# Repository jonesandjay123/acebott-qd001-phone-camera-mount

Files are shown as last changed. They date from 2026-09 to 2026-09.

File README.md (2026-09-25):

# ACEBOTT QD001 Phone Camera Mount

3D-printable, one-piece phone mount for the ACEBOTT QD001 mecanum-wheel robot car.
The phone stands upright (90°) above the battery box so its **rear camera works as the
car's forward-looking camera**; the screen faces the rear of the car.

Designed for a **Bambu Lab A1 mini**, printed upright with **no supports**.

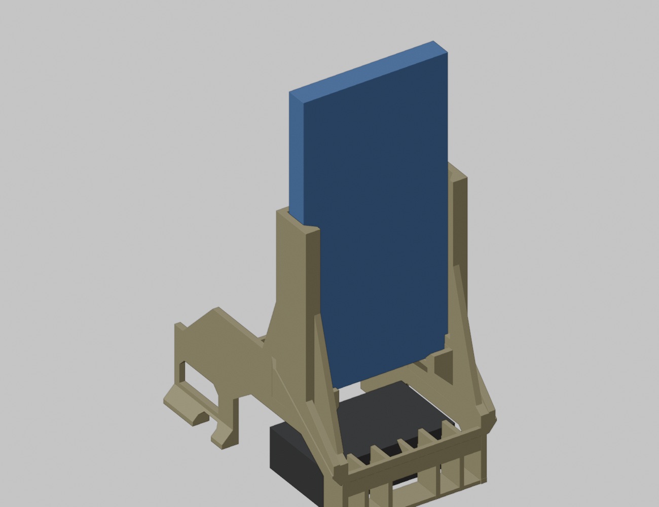
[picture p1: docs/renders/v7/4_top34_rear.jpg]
V7 rear view with phone


## Files

| Path | What it is |
|---|---|
| `models/current/ACEBOTT_QD001_PhoneMount_V7_90deg_OnePiece.stl` | **Print this.** V7, fixed 90°, one piece, 104.3 cm³, 91 × 138 × 150 mm |
| `models/current/spoiler_v9_fable_v7.blend` | Blender source of V7 (object `V7_Body`) |
| `models/legacy/ACEBOTT_QD001_PhoneMount_V6_…_DO-NOT-PRINT.stl` | V6 — tower stood on the mast and blocked the wire bundle. Kept for reference only |
| `models/legacy/FableV4_OnePiece.stl` | V4 — 35° "spoiler" version. Printed and installed; its lower half is the verified base that V6 is built on |
| `models/legacy/spoiler_v7_fable_v5_stepped-angle-concept.blend` | V5 concept: 100° tower with a 3-step (90/95/100°) tread floor. Superseded by V6 |
| `docs/DESIGN_NOTES.md` | Geometry, constraints, load path, what was verified on the real car |
| `docs/PRINTING.md` | Slicer settings, orientation, risk notes |
| `docs/images/` | Photos of V4 on the car and the annotated side view used to plan V6 |
| `docs/renders/` | Blender renders of V7, V6 and the V5 concept |
| `reference/scripts/` | Python used in Blender to build/check/export the parts (`build_v7.py` reproduces V7 from the V4 STL) |
| `reference/photos/` | Full-size photos of V4 installed |

## Phone

Sized for a Pixel with a case: slot **81.5 mm** wide, **18.5 mm** deep, phone bottom ~54 mm above
the upper chassis plate. The top ~55 mm of the phone (camera bar) is left completely free.
USB‑C cable exits downward through the open centre of the floor.

## Status

- V4: printed, installed, verified fit (USB‑C window, screw notches, battery bay, wiring).
- V6: never printed — its tower sat inside the wire-bundle space in front of the mast (see `docs/DESIGN_NOTES.md`, "Wire keep-out").
- V7: tower moved behind the mast; wire chamber proven empty by boolean check. Geometry verified in software only (watertight, no islands, bridges as V4 plus one 30 mm arch). **Not yet printed.**

## License

MIT — see `LICENSE`.

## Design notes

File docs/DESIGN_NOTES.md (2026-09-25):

# Design notes

## Origin
The mount started as a cardboard prototype built directly on the car, 3D-scanned, and turned into a
printable part (V1–V4, 35° deck). V4 was printed and installed; its lower half (side walls, USB‑C
window, screw-head notches, battery arches, DC-plug window, rear fins) is treated as verified and is
reused unchanged by every later version — later versions are built by importing `FableV4_OnePiece.stl`
into Blender and cutting/adding geometry (`reference/scripts/build_v6.py`).

## Why 90°
With the phone lying at 35° its rear camera points at the ceiling. For the camera to look forward the
phone must stand upright. V6 is fixed at 90°; V5 explored 100° with three tread positions but was
dropped to keep the part simpler and lighter.

## Key dimensions (Z = 0 at the upper plate top)
| Feature | Value |
|---|---|
| Side walls | X ±36.3 … ±39.5 (3.2 mm), Y −92 … +51 |
| Battery bay | Y −76 … −28, roof Z 22.5 (right) / gable to 35.5 (left, includes DC plug zone to Y −2) |
| USB‑C window (left wall) | Y 10 … 42, Z 11 … 25 |
| Screw-head notches | Y 7 … 22, Z 0 … 7.5, both walls |
| Mast (transverse wall) | Y −20 … −17.6, Z 32 … 65, wire arch Z 32 … 54, 34 mm wide |
| Tower plate (V7) | Y −48 … −44.6, arched bottom (springs Z 37 at the walls, 30 mm bridge at Z 58.2), plate Z 60 … 150, X ±44.25; pentagon window X ±22, Z 66 … 138 |
| Phone slot | width 81.5, depth 18.5, lips at X ±36.25, phone bottom Z 54 |
| Bottom groove | Y −62 … −48 (14 mm), pads X 25.5 … 40.75 each side; lips Y −66.5 … −69 |
| Front gussets | X ±36.2 … ±39.6 on the bay walls, Y −45.6 … −26, apex Z 118 (behind the mast) |
| Rear gussets | same walls behind the lips, Y −69 … −88, apex Z 105 |
| Rear fins | 5 × 2.4 mm at X 0, ±13, ±26, Y −92 … −76.5, Z 0 … 30, on a 2 mm pad, tied by the band at Y −92 |

## Load path
Phone → arched tower plate (vertical, in-plane stiff sideways; its arch ties the two bay walls)
→ front gussets on the bay walls (in-plane stiff fore/aft) → walls → feet. Rails + plate form a C
channel; rear gussets behind the lips stop the rails bending outward. Transverse ties: mast (front),
arched tower plate (middle), tie band + fins (rear).

## Clearances that must stay
- Nothing inside X ±36, Z < 31 over the battery (battery slides out sideways).
- Left wall Y −22 … −2 open below Z 25 for the DC plug.
- **Wire keep-out (learned the hard way with V6):** the Dupont bundle from the board headers loops up
  to ~Z 100–110 and forward to the ultrasonic module, entirely INSIDE the chamber in front of the mast.
  Nothing may occupy X ±36.25 / Y > −17.55 / Z > 40, nothing above Z 65 in front of the mast, and
  nothing beyond Y 46 (front module). `build_v7.py` proves this with boolean intersections = 0.
  The chamber could shrink ~10 mm per side if ever needed, but the structure must live behind the mast.
- Phone camera bar (top ~55 mm of the phone) must not be covered — tower top is at Z 150 = 96 mm above the phone bottom.

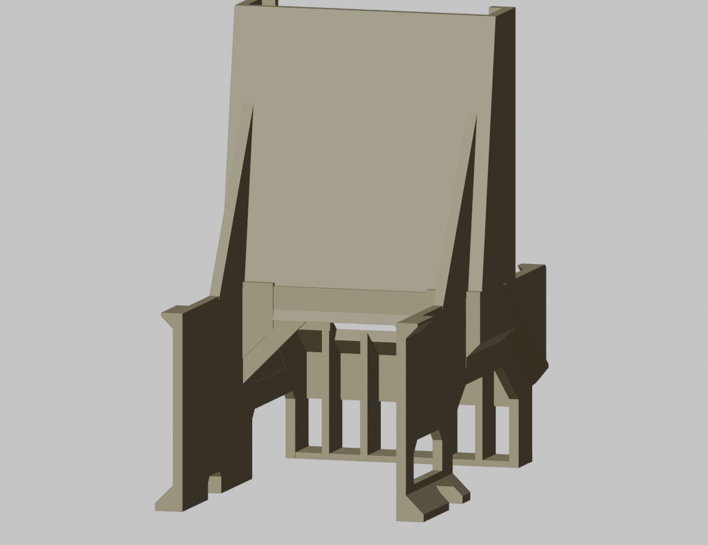
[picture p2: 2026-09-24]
docs/renders/v5_stepped_concept/6_front_low.jpg

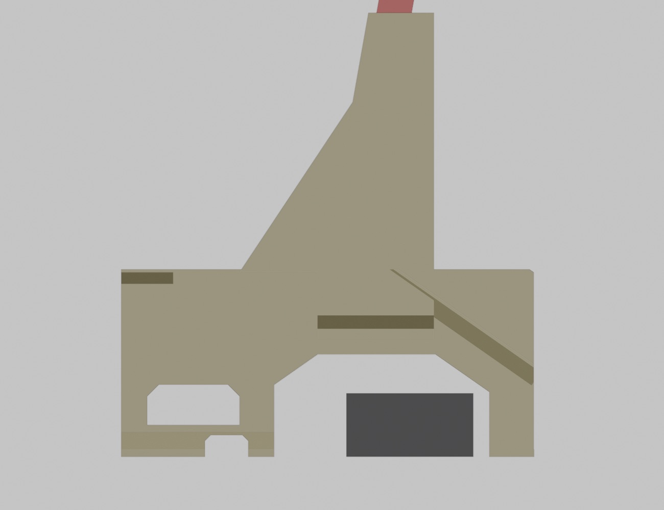
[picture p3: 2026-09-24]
docs/renders/v5_stepped_concept/3_side_left_phone100.jpg

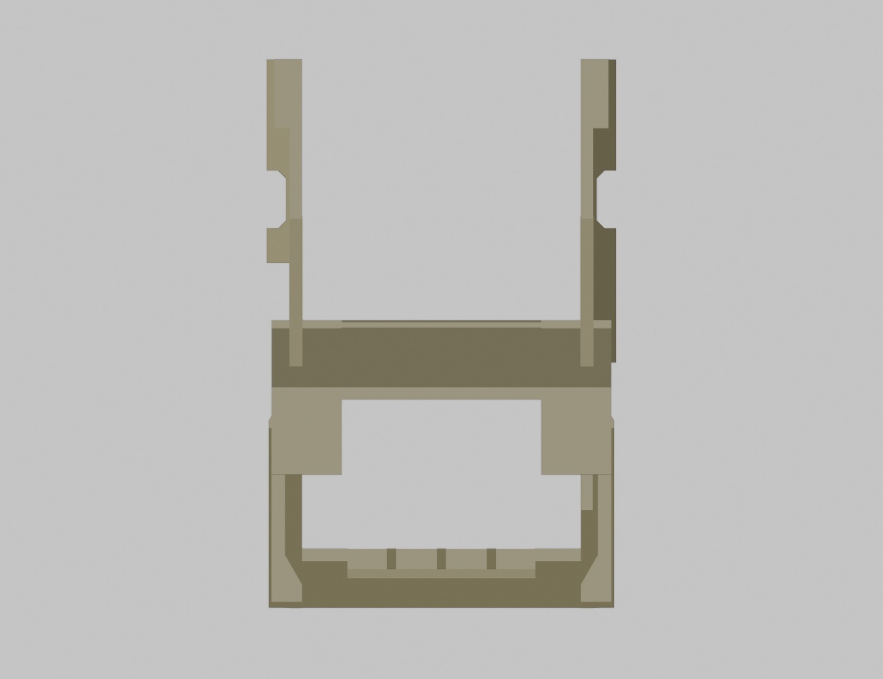
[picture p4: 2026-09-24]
docs/renders/v5_stepped_concept/4_top.jpg

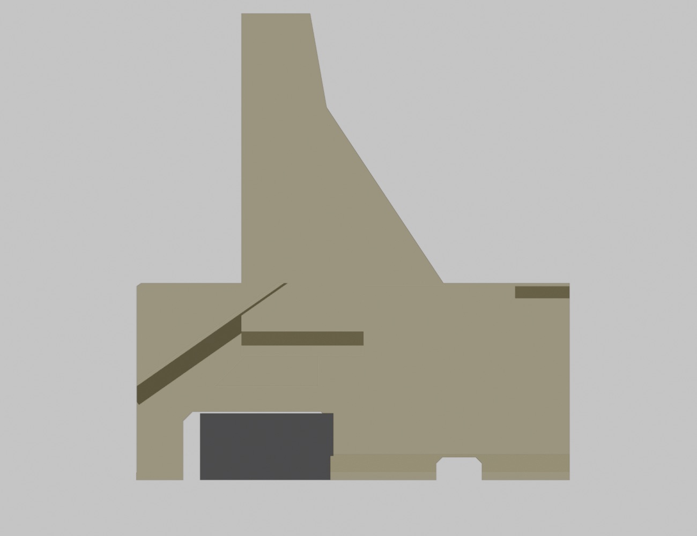
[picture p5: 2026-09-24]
docs/renders/v5_stepped_concept/3c_side_right.jpg

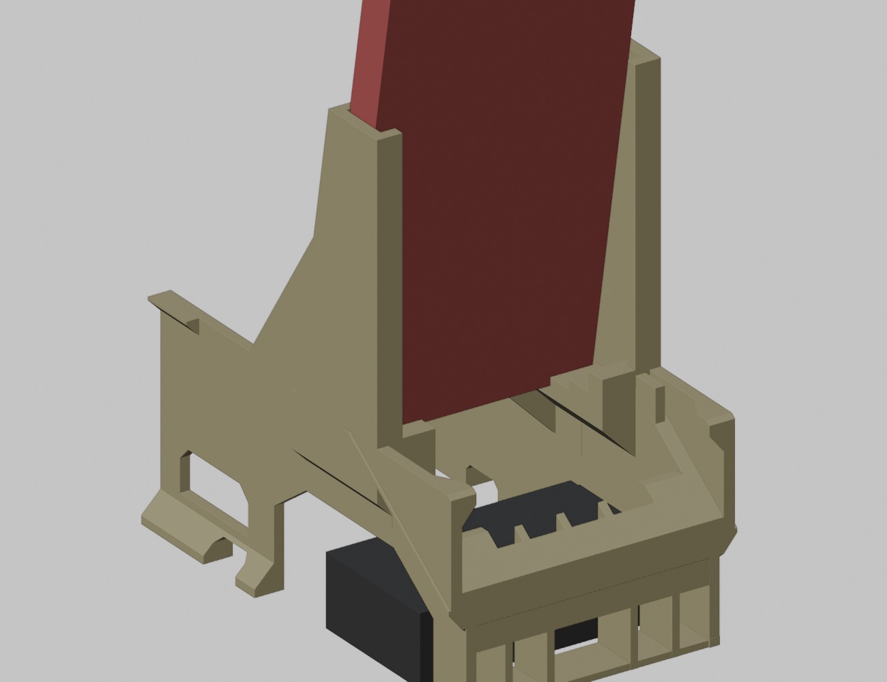
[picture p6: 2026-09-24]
docs/renders/v5_stepped_concept/2b_rear34_phone100.jpg

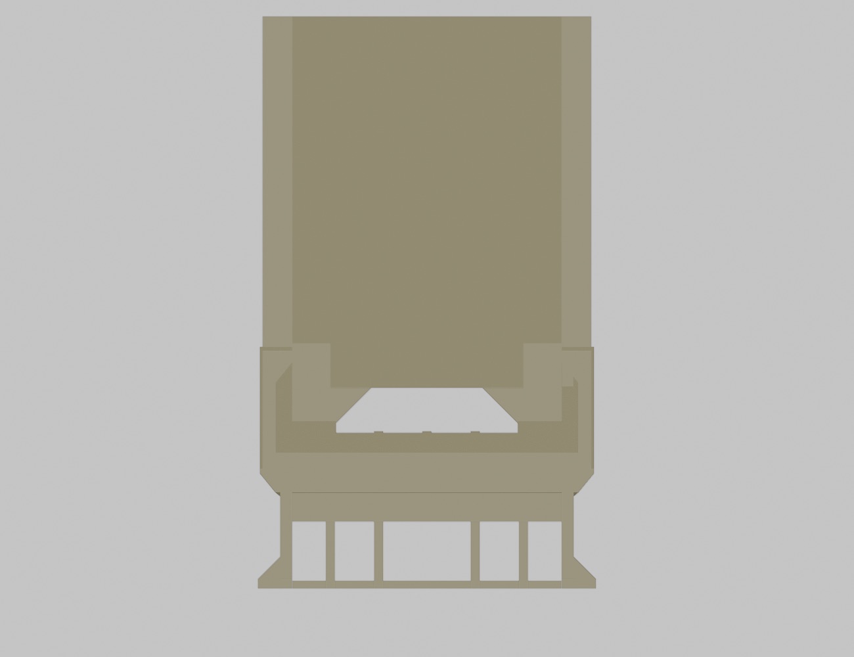
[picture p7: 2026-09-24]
docs/renders/v5_stepped_concept/8_rear_straight.jpg

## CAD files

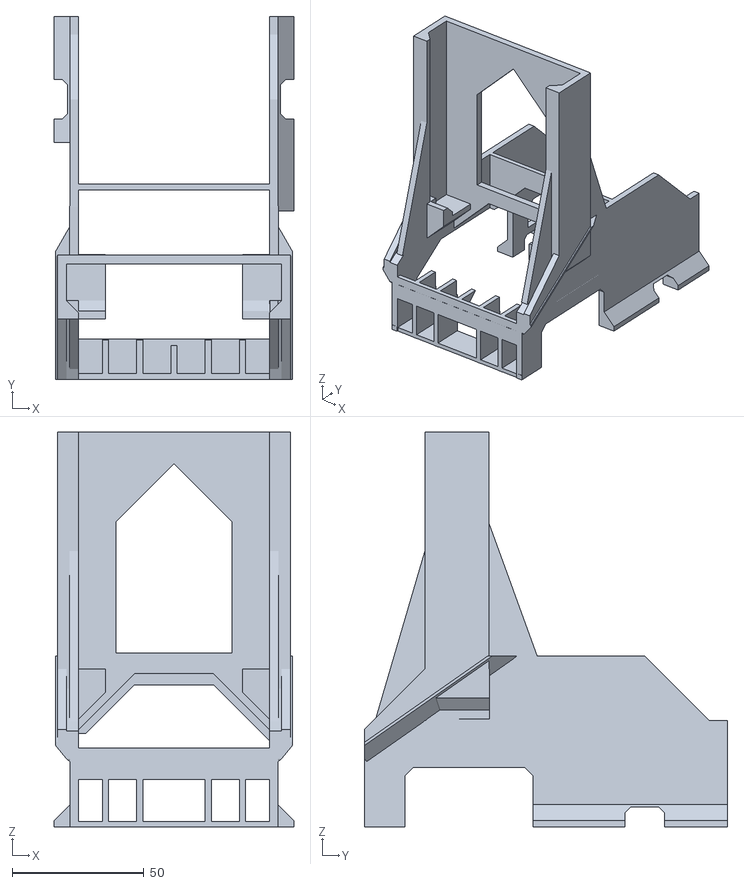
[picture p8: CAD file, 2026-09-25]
models/current/ACEBOTT_QD001_PhoneMount_V7_90deg_OnePiece.stl
91.0 x 138.0 x 150.0

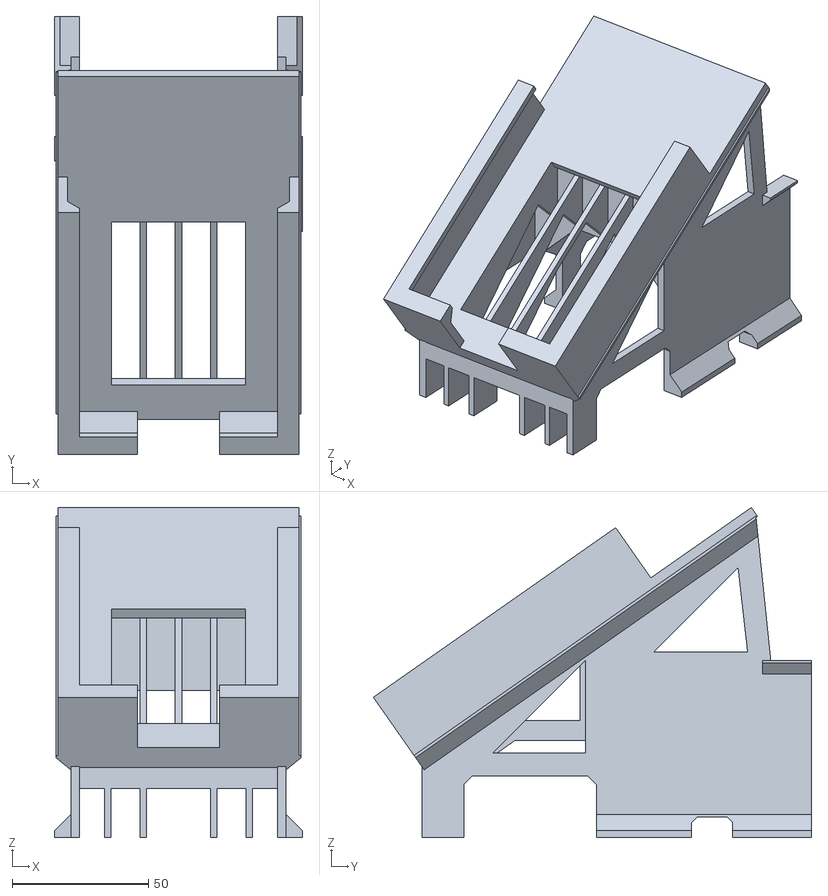
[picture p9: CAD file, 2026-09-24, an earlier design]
models/legacy/FableV4_OnePiece.stl
91.0 x 160.8 x 121.0

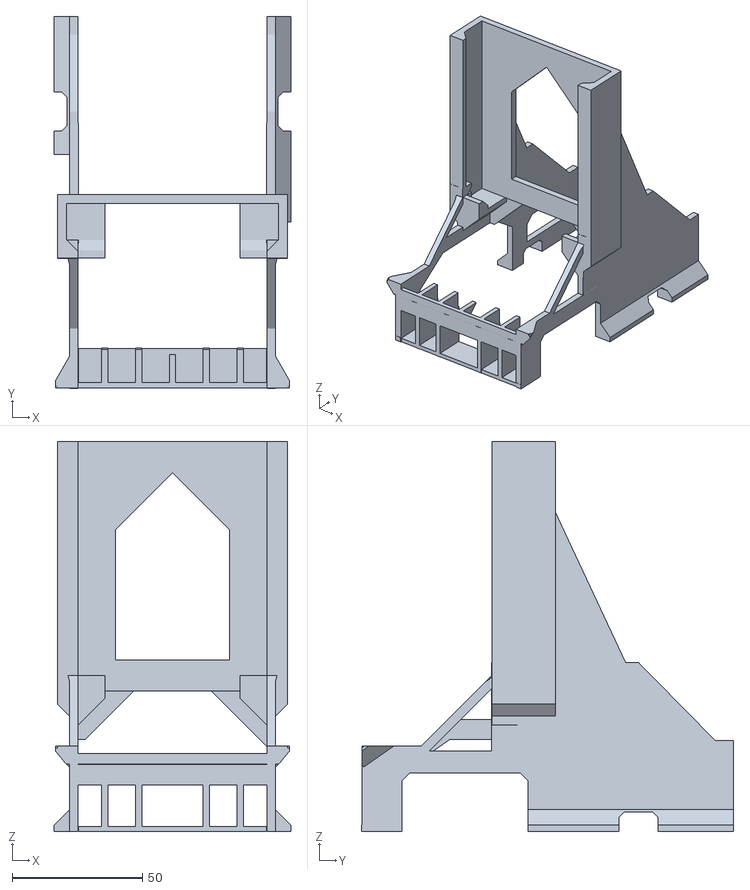
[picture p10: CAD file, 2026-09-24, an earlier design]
models/current/ACEBOTT_QD001_PhoneMount_V6_90deg_OnePiece.stl
91.0 x 143.0 x 150.0

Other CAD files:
models/current/spoiler_v8_fable_v6.blend
models/current/spoiler_v9_fable_v7.blend
models/legacy/spoiler_v7_fable_v5_stepped-angle-concept.blend
models/legacy/spoiler_v8_fable_v6.blend

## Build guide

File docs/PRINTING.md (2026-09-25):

# Printing (Bambu Lab A1 mini)

- File: `models/current/ACEBOTT_QD001_PhoneMount_V7_90deg_OnePiece.stl`
- Orientation: as exported — flat base on the bed, tower up. Do **not** rotate. Height 150 mm.
- Supports: **off**. Every overhang is ≤ 45° or a bridge that already printed fine on V4
  (42 mm battery-bay roof, 41 mm left gable, 34 mm mast arch, 32 mm USB‑C window, 23 mm tie band) plus the tower's 30 mm arch bridge at Z 58.
- Brim: 5 mm recommended (tall part, bed-slinger).
- Layer height: 0.28 mm "Extra Draft"-type profile is fine; 0.2 mm for nicer phone-contact faces.
- Walls: 3 perimeters. Most walls are 3.2–3.5 mm and print nearly solid; infill setting barely matters.
- Material: PLA/PLA+ or PETG. ~120 g PLA estimated. Time roughly 3–4.5 h at 0.28 mm (about 0.7× the V4 print).

## What to check after printing
1. Wire bundle loops freely in front of the mast; nothing touches it.
2. Phone slides in from the top and sits on the two floor pads; USB‑C plug fits through the centre gap.
3. Battery still slides out sideways under the arches.
4. DC plug / cable pass through the left-side window.
5. If the phone rattles at the lips (6.5 mm play at 90°), add a 1–2 mm felt/foam strip on the plate,
   or ask for a 2–3° rearward-lean variant.

## Design rules used (keep them for future edits)
- One piece, no sacrificial posts, no long free-standing columns.
- A continuous grounded footprint first; structure branches upward from existing walls.
- New overhangs only as 45° haunches/flares or gable tops — no new flat bridges.
- Verify with the voxel island check in `reference/scripts/lib_v5.py` (`printcheck`) before exporting.

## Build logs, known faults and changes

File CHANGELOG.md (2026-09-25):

# Changelog

Coordinate frame used everywhere: X right, Y toward the car front, Z up, Z = 0 at the top of the
upper chassis plate (same as the STL files).

## V7 — 2026-09-24 (current, not yet printed)
- V6 was blocked before printing: on the car the wire bundle from the board headers loops up and forward inside the chamber in front of the mast; V6's tower plate (Y −20.9) and its gussets on the front wall tops sat inside it.
- Tower moved behind the mast: arched bulkhead at Y −48 … −44.6 (45° haunches from Z 37 to a 30 mm bridge at Z 58.2, plate Z 60 … 150), rails/lips Y −48 … −69, floor groove Y −62 … −48.
- Front gussets now on the battery-bay walls (Y −45.6 … −26, apex Z 118); rear gussets behind the lips (apex Z 105).
- Mast kept at the V4 height (Z 65). Front walls dropped to Z 40.5 beyond Y 39 and cut at Y 46. V4 wall windows filled. Rear tail 45° from (Y −69, Z 60).
- Keep-out proven by boolean intersection = 0: chamber X ±36.25 / Y > −17.55 / Z > 40; anything above Z 65 in front of the mast; anything beyond Y 46.
- 104.3 cm³. Islands 0, bridges = V4 + 30 mm arch, bed contact 1991 mm².

## V6 — 2026-09-24 (superseded, never printed)
- Fixed 90° vertical phone tower rooted in the V4 transverse "mast" wall (Y −20.9 … −17.5, Z 54 … 150).
- Phone slot: V4-verified 81.5 mm width, lips ±36.25 mm, 45° rail chamfer, 2.5 mm lips; depth reduced 20 → **18.5 mm**.
- Bottom groove 14 mm with 45° lead-in; floor pads 15 mm each side, 51 mm centre gap for USB‑C.
- Front gussets on the side-wall tops (Z 64 → 125), side trays with 45° haunch/flare, pentagon lightening window in the plate.
- Removed: 35° deck, deck ribs, corbel behind the tie band, V5 tread steps.
- Trimmed: rear walls to a 45° tail (Z 33), front walls to Z 35 beyond Y 14, rear fin comb to Z 30; 2 mm grounded pad under the fins.
- 93.4 cm³ (V4 150.5, −38 %). Islands 0, bridges identical to V4 (42/41/34/32/23 mm), bed contact 2080 mm².

## V5 — 2026-09-24 (concept only)
- 100° leaning tower with a 3-step tread floor giving 100/95/90° without moving parts. Dropped in favour of a fixed 90° (simpler, less rattle risk, lighter).

## V4 — 2026-09-19 (printed, installed)
- 35° deck ("spoiler") version with weight reduction (deck window, 2.4 mm mast and fin-ribs, wall windows). 150.5 cm³.
- Verified on the car: USB‑C window, mid screw notches, battery bays, wiring, DC-plug clearance.

## V1–V3 — 2026-09-18
- Reconstruction from the cardboard prototype scan; battery arches, screw-head notches, rear fins + tie band, one-piece printing without supports.

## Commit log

2026-09-24 Initial import: ACEBOTT QD001 phone camera mount V6 (fixed 90°) with V4/V5 history, docs, renders and build scripts
    [ACEBOTT_QD001_PhoneMount_V6_90deg_OnePiece.stl, FableV4_OnePiece.stl, spoiler_v7_fable_v5_stepped-angle-concept.blend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]
2026-09-25 V7 WIP: move tower behind the mast to keep the V4 wire chamber free (not yet exported/printed)
    [spoiler_v9_fable_v7.blend]
2026-09-25 V7: export STL, retire V6 to legacy, update README/CHANGELOG/docs with wire keep-out
    [ACEBOTT_QD001_PhoneMount_V6_90deg_OnePiece_DO-NOT-PRINT.stl, ACEBOTT_QD001_PhoneMount_V7_90deg_OnePiece.stl, spoiler_v8_fable_v6.blend]
